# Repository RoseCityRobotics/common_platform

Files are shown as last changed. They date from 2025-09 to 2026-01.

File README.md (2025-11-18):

# Rose City Robotics Common Platform

> 📚 **📖 [View Complete Documentation](https://common.rosecityrobotics.com/)** - Comprehensive guides for setup, operation, and development

<!-- ABOUT THE PROJECT -->
## A Fork of the PARTS Common Platform

<br>
<p align="center">
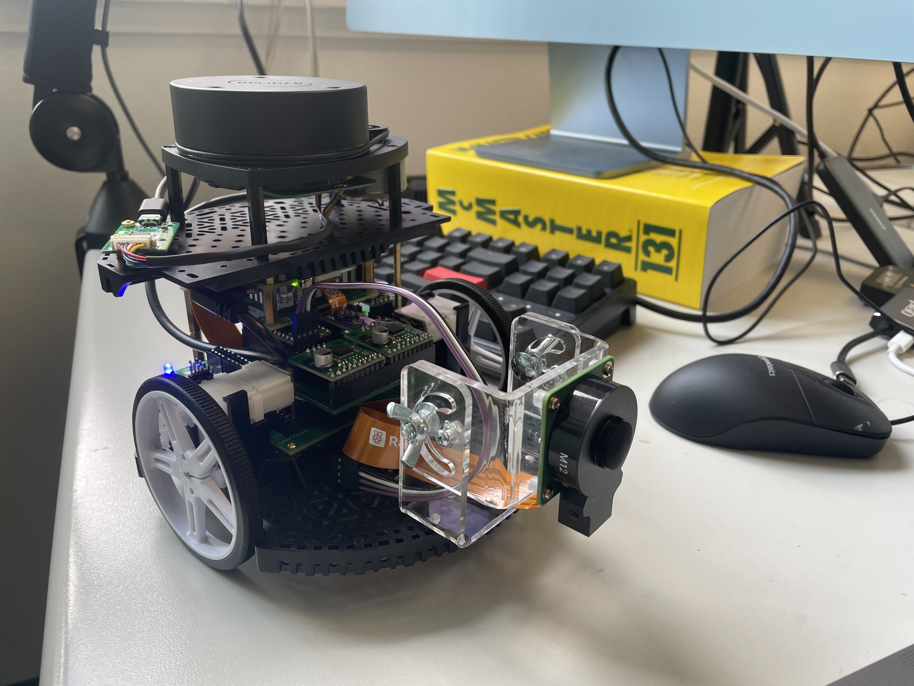
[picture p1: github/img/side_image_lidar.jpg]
Side view with LiDAR sensor
  
</p>
<br>

This project implements a complete robotics platform built on the Pololu Romi Chassis Kit, featuring a custom carrier PCB that integrates all components into a compact, efficient design. The platform combines hardware, firmware, and software to create a fully functional autonomous robot.

<br>
<p align="center">
  <a href="https://portlandrobotics.org/home.php?link_id=1">
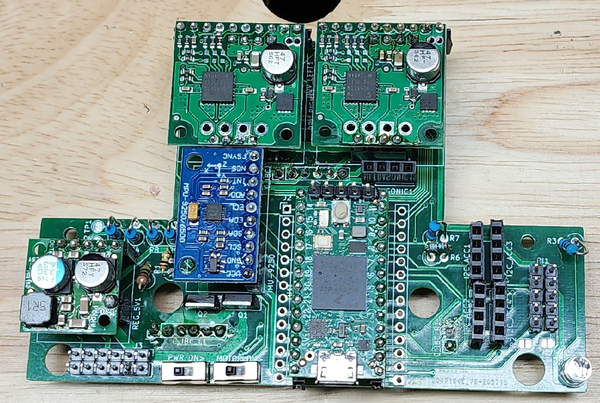
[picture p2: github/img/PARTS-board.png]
    
  </a>
<br>
<br>

**Hardware Components:**
- **Pololu Romi Chassis Kit** - Robust base platform with encoders and caster
- **Custom PARTS CRP Board** - Integrated carrier PCB with all connections
- **Teensy 4.0 Microcontroller** - High-performance ARM Cortex-M7 processor
- **TB9051FTG Motor Drivers** - Dual brushed DC motor control
- **MPU-9250 9DOF IMU** - Nine-axis motion sensing for navigation
- **Raspberry Pi with AI HAT** - Main computer for ROS2 and onboard autonomous vision inferance at 26 TOPS
- **Power Management** - 5V regulator and battery voltage monitoring

<br>
<p align="center">
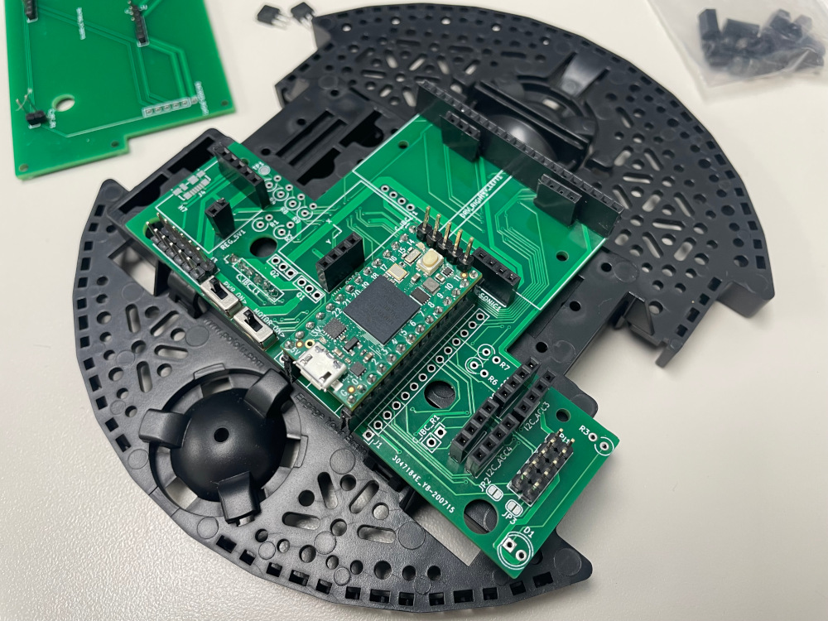
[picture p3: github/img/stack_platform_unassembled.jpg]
Mobile base platform
  
</p>
<br>

**Current Implementation:**
The platform now features a complete ROS2 integration with micro-ROS running on the Teensy 4.0, enabling real-time communication between the Raspberry Pi and the robot's sensors and actuators. The system supports autonomous navigation, sensor fusion, and closed-loop control, making it an ideal platform for robotics education and development in the Portland Area Robotics Society.

<p align="right">(<a href="#readme-top">back to top</a>)</p>

### Built With

* [][cpp-url]
* [][c-url]
* [][python-url]
* [][platformio-url]
* [][arduino-url]
* [][kicad-url]
* [][ros-url]

<p align="right">(<a href="#readme-top">back to top</a>)</p>

<!-- GETTING STARTED -->
## Getting Started

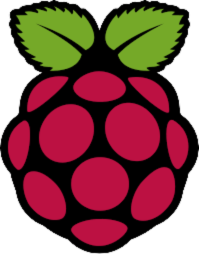
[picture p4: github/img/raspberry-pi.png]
Raspberry Pi
###  Direct Connection to Raspberry Pi
Connect your micro HDMI cable to your Pi and monitor, and a keyboard to the USB-A port.

OR

### 🖥️ On the development computer: Connect via SSH:
   ```bash
   ssh rcr@192.168.1.n
   ```
   Replace `n` with your robot number.

### Raspberry Pi Ubuntu Login on Raspberry Pi
- **User:** `rcr`
- **Password:** `siliconforest`

## 📚 Documentation

> **📖 [Complete Documentation](https://common.rosecityrobotics.com/)** - Comprehensive guides for setup, operation, and development

### Key Documentation Sections

- **🚀 [Getting Started](https://common.rosecityrobotics.com/)** - Complete setup from hardware assembly to first robot movement
- **⚙️ [Hardware Assembly](https://common.rosecityrobotics.com/hardware.html)** - Step-by-step soldering and assembly instructions
- **💻 [Software Setup](https://common.rosecityrobotics.com/setup/index.html)** - Host configuration, ROS2 installation, and Teensy programming
- **🎮 [Robot Operations](https://common.rosecityrobotics.com/operations/index.html)** - Startup, shutdown, teleoperation, and navigation procedures
- **🧪 [Testing & Validation](https://common.rosecityrobotics.com/testing.html)** - Smoke tests and system verification
- **🔧 [Troubleshooting](https://common.rosecityrobotics.com/operations/troubleshooting/index.html)** - Common issues and recovery procedures

### Quick Start Highlights

- **Hardware**: Custom PARTS CRP board with integrated motor drivers and Teensy 4.0
- **Software**: ROS2 with micro-ROS for real-time communication
- **Sensors**: LiDAR, IMU, and camera support for autonomous navigation
- **Programming**: Arduino CLI for Teensy firmware development
- **Testing**: Basic smoke test to verify hardware functionality

<p align="right">(<a href="#readme-top">back to top</a>)</p>

## 🤖 Imitation Learning Training

The platform includes a complete PyTorch training pipeline for robot maze navigation using imitation learning with a transformer-based architecture. For detailed documentation, see [`scripts/imitation_learning/src/imitation_learning/README.md`](scripts/imitation_learning/src/imitation_learning/README.md).

### Transfer Learning from No-Z Model Checkpoint

If you have a previously trained model without the Z variable (CVAE style variable) and want to initialize a new model with Z using those weights, you can use transfer learning:

```bash
# Navigate to the imitation learning directory
cd scripts/imitation_learning/src/imitation_learning

# Train with transfer learning from a no-Z model checkpoint
python train.py \
  --config config.yaml \
  --transfer_from_noz /path/to/best_model_without_z.pth
```

**What gets transferred:**
- ✅ Vision encoder weights
- ✅ Temporal encoder weights  
- ✅ Action decoder weights
- ✅ Action queries and action head weights
- 🆕 New CVAE components (`action_encoder`, `z_projection`) are randomly initialized

**Optional: Freeze layers during transfer learning**

You can freeze specific layers while training the new CVAE components by enabling transfer learning in your config:

```yaml
# In config.yaml
transfer_learning:
  enabled: true
  freeze_vision: true      # Freeze vision encoder
  freeze_encoder: false     # Keep temporal encoder trainable
  freeze_decoder: false     # Keep action decoder trainable
```

**Example: Freeze vision encoder only**
```bash
python train.py \
  --config config.yaml \
  --transfer_from_noz checkpoints/best_model_noz.pth
```

With `freeze_vision: true` in the config, the vision encoder will remain frozen while the new CVAE components and other layers are trained.

For more training options and examples, see the [imitation learning README](scripts/imitation_learning/src/imitation_learning/README.md).

<p align="right">(<a href="#readme-top">back to top</a>)</p>

### Assembly Images

*Mobile base platform - unassembled components*

Mobile base platform

*Assembled chassis with controller*

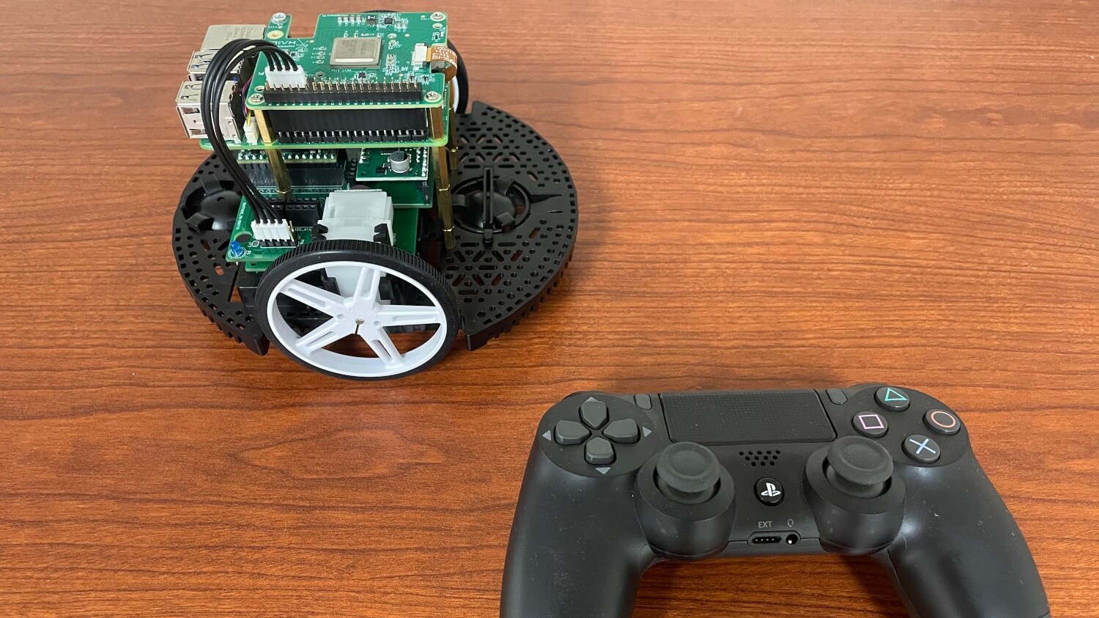
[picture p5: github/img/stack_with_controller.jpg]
Mobile base platform assembly


*Custom PCB showing integrated motor drivers and controller connections*

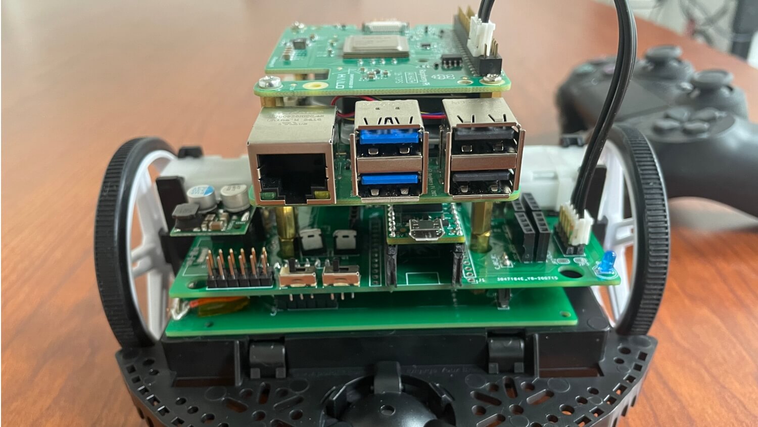
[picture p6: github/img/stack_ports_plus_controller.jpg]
Custom PCB with ports and controller


*Completed chassis - top view with Raspberry Pi AI HAT+*

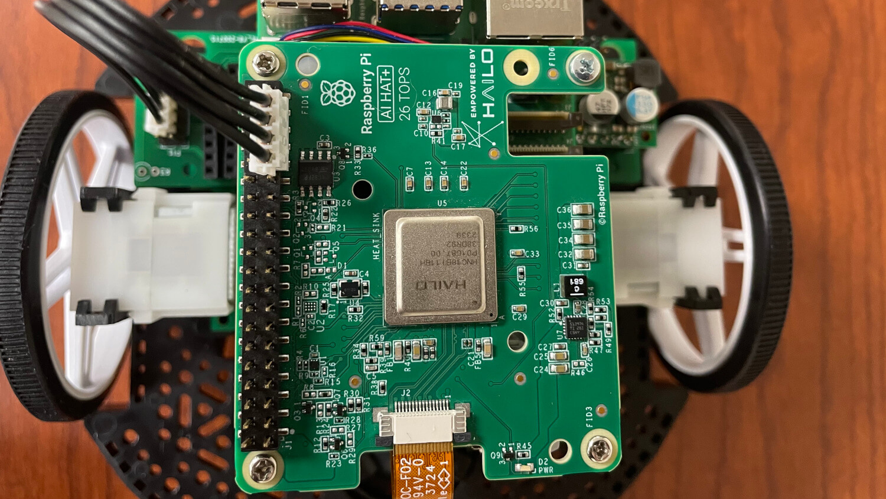
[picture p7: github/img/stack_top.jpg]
Assembled Platform - Top View


*Raspberry Pi 5 with AI HAT+*

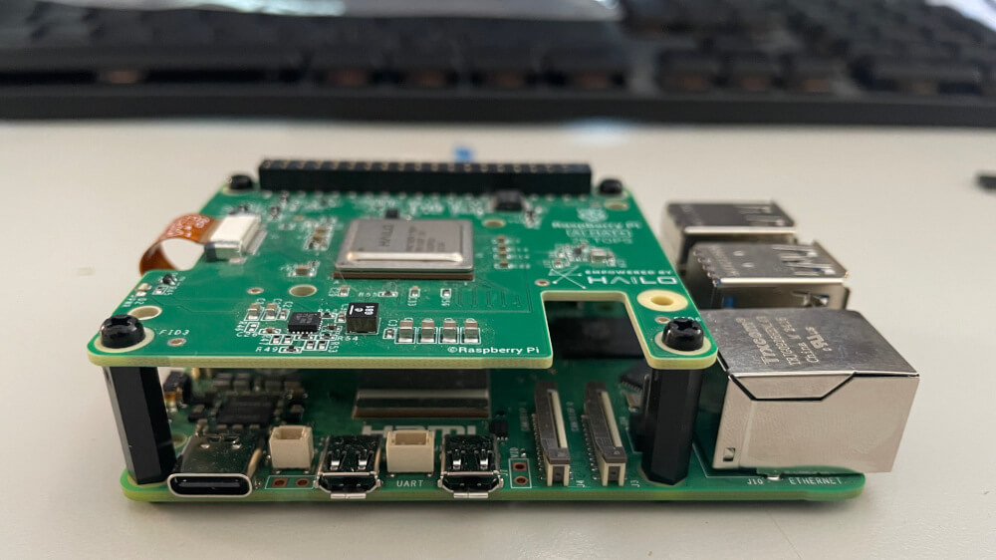
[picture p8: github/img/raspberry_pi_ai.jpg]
Raspberry Pi 5 with AI HAT+


*Side view with LiDAR sensor mounted*

Side view with LiDAR sensor

<p align="right">(<a href="#readme-top">back to top</a>)</p>

See the [open issues](https://github.com/rosecityrobotics/common_platform/issues) for a full list of proposed features (and known issues).

<p align="right">(<a href="#readme-top">back to top</a>)</p>

### Thank you PARTS

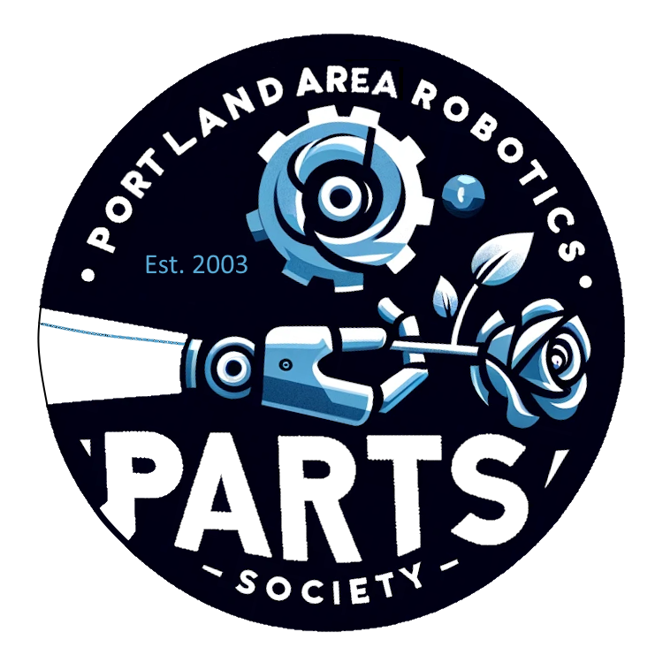
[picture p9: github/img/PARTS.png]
Portland Area Robotics Society (P.A.R.T.S.)


*Portland Area RoboTics Society (PARTS)*
Our work is based on the [PARTS Common Platform](https://github.com/portlandrobotics/common_platform)

<!-- CONTRIBUTING -->
## Contributing

Contributions are what make the open source community such an amazing place to learn, inspire, and create. Any contributions you make are **greatly appreciated**.

If you have a suggestion that would make this better, please fork the repo and create a pull request. You can also simply open an issue with the tag "enhancement".
Don't forget to give the project a star! Thanks again!

1. Fork the Project
2. Create your Feature Branch (`git checkout -b feature/AmazingFeature`)
3. Commit your Changes (`git commit -m 'Add some AmazingFeature'`)
4. Push to the Branch (`git push origin feature/AmazingFeature`)
5. Open a Pull Request

<p align="right">(<a href="#readme-top">back to top</a>)</p>

<!-- LICENSE -->
## License

Distributed under the MIT License and the Solderpad Hardware License v2.1. See [LICENSE.txt][license-url] for more information.

<p align="right">(<a href="#readme-top">back to top</a>)</p>

<!-- MARKDOWN LINKS & IMAGES -->
<!-- https://www.markdownguide.org/basic-syntax/#reference-style-links -->
[contributors-shield]: https://img.shields.io/github/contributors/portlandrobotics/common_platform.svg?style=for-the-badge
[contributors-url]: https://github.com/portlandrobotics/common_platform/graphs/contributors
[forks-shield]: https://img.shields.io/github/forks/portlandrobotics/common_platform.svg?style=for-the-badge
[forks-url]: https://github.com/portlandrobotics/common_platform/network/members
[stars-shield]: https://img.shields.io/github/stars/portlandrobotics/common_platform.svg?style=for-the-badge
[stars-url]: https://github.com/portlandrobotics/common_platform/stargazers
[issues-shield]: https://img.shields.io/github/issues/portlandrobotics/common_platform.svg?style=for-the-badge
[issues-url]: https://github.com/portlandrobotics/common_platform/issues
[license-shield]: https://img.shields.io/badge/license-mit_%26_solderpad-brightgreen?style=for-the-badge
[license-url]: https://github.com/portlandrobotics/common_platform/blob/master/LICENSE.txt
[arduino-ide]: https://img.shields.io/badge/Arduino_IDE-00979D?style=for-the-badge&logo=arduino&logoColor=white
[arduino-url]: https://www.arduino.cc/en/software
[cpp]: https://img.shields.io/badge/C%2B%2B-00599C?style=for-the-badge&logo=c%2B%2B&logoColor=white
[cpp-url]: https://en.wikipedia.org/wiki/C%2B%2B
[c]: https://img.shields.io/badge/C-00599C?style=for-the-badge&logo=c&logoColor=white
[c-url]: https://en.wikipedia.org/wiki/C_(programming_language)
[python]: https://img.shields.io/badge/Python-3776AB?style=for-the-badge&logo=python&logoColor=white
[python-url]: https://www.python.org/
[platformio]: https://img.shields.io/badge/PlatformIO-F5822A.svg?style=for-the-badge&logo=PlatformIO&logoColor=white
[platformio-url]: https://platformio.org/
[kicad]: https://img.shields.io/badge/KiCad-314CB0.svg?style=for-the-badge&logo=KiCad&logoColor=white
[kicad-url]: https://www.kicad.org/
[ros]: https://img.shields.io/badge/ROS-22314E.svg?style=for-the-badge&logo=ROS&logoColor=white
[ros-url]:https://www.ros.org/

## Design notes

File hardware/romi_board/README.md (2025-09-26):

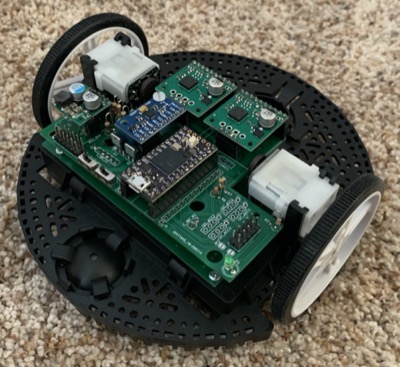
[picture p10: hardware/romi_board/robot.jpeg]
robot


## Assembly Notes

- In general, follow the instructions in the Romi chassis assembly [guide](https://www.pololu.com/docs/0J68/4).  Note that wheel encoders should be installed as shown in those instructions and will plug into the bottom board.
- The [interactive BOM](https://htmlpreview.github.io/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) is helpful while soldering components onto the board.
- We recommend using headers between the boards so that disassembly is possible.  Use female (socket) header on the bottom board and male (pin) headers on top board.  Pin headers come with all of the breakout boards.  
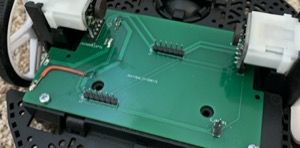
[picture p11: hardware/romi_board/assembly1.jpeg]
assembly1
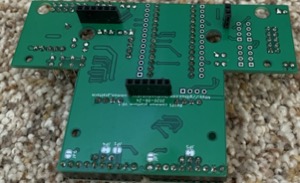
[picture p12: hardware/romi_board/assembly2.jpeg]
assembly2
 
- Use the top board to guide breakout board header soldering.  Insert the pin headers into the appropriate positions on the top board and then add the breakout boards onto the pins and solder them to the breakout boards. 
We recommend using socket headers on the top board for all of the breakout board positions so that they can be plugged in- Brace the IMU with extra header or cardboard or some other means.  Shown below is a 3D printed block but anything of the appropriate size will do.  
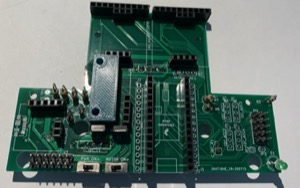
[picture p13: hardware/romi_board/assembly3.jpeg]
assembly3

- The three pin header on the motor driver is not needed and can be left without header pins.
- Pay attention to the orientation of the MOSFETs
- Use 2M ohm resistor for the battery voltage resistor divider (R1) if you use the 6 AA batteries.  If you use higher voltage batteries (2 LiPo batteries for example) then use a 3M ohm resistor.
- Cut trace on teensy for battery power.  See the note "Cut to separate VIN from VUSB" on the "Teensy 4.0 Back Side" image on this [page](https://www.pjrc.com/store/teensy40.html).
- If you want to mount a Raspberry Pi on the robot, this is how to use standoffs to do so:  
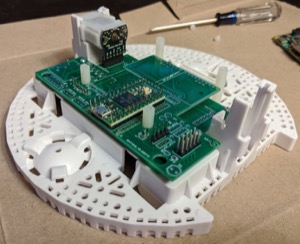
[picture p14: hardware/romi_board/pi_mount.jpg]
pi


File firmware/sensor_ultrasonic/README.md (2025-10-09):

# Ultrasonic Sensor Test

## Overview
This project involves using an Arduino/Teensy to test an HC-SR04 ultrasonic sensor. The `ultrasonic_test.ino` sketch measures the distance to an object and prints the result to the Serial Monitor.

## Requirements
- Arduino Compatible Device (Teensy, Uno, Mega, or similar)
- HC-SR04 Ultrasonic Sensor
- Jumper Wires

## Wiring
Connect the ultrasonic sensor to the Teensy 4.0:
- VCC to 5V
- GND to GND
- TRIG to Pin 9
- ECHO to Pin 15

OR

- Hook sensor to ULTRASONIC1 on Common Robotics Platform Main Board. Pin 1 VCC, Pin 2 Trigger, Pin 3 Echo, Pin 4 Ground. Looking at the RCR Common Robotics Platform board from the top, find the label "ULTRASONIC1" - Pin 1 is toward the U on ULTRASONIC1.
  - Ensure R6 3.3k and R7 4.6k resistors are installed so we don't burn out the teensy.

## Installation
1. Connect the Teensy/Arduino to your computer.
2. Open the `ultrasonic_test.ino` sketch in the Arduino IDE.
3. Upload the sketch to your Arduino board.

## Usage
After uploading the sketch, open the Serial Monitor in the Arduino IDE. You should see distance measurements displayed in centimeters, updated approximately every half second.

## Troubleshooting
- Ensure all connections are secure.
- Verify that the correct COM port is selected in the Arduino IDE.
- Ensure that your Arduino board is compatible with the sketch.

For more information or assistance, refer to the documentation of the HC-SR04 ultrasonic sensor and the Teensy/Arduino board being used.

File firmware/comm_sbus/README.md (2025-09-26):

# SBUS Test Readme

## Overview

The SBUS (Serial Bus) protocol is a digital communication protocol used in remote control equipment, particularly for communicating with RC (radio controlled) servos. It is favored for its efficiency and capability to handle multiple channels over a single wire. This README guides you through integrating SBUS control with our PARTS Robot using the [bolderflight/sbus](https://github.com/bolderflight/sbus) library.

Our project leverages the SBUS protocol to enable precise and responsive control over the PARTS Robot. By using SBUS, we can efficiently manage multiple control signals, such as steering and throttle, through a single digital connection. This approach simplifies wiring, increases reliability, and enhances the overall responsiveness of the robot. The SBUS library by Bolder Flight Systems provides a convenient and robust way to implement SBUS communication in our system, especially when interfaced with a Teensy microcontroller.

## Prerequisites
- A working installation of Teensy microcontroller.
- Basic understanding of SBUS communication protocol.
- A compatible SBUS transmitter and receiver.

## Installation and Setup

1. **Library Installation**: Download and install the sbus library from [bolderflight/sbus](https://github.com/bolderflight/sbus).

2. **Hardware Connection**: 
   - Connect the SBUS out on your receiver to an open Serial RX port on your Teensy. 
   - In this example, RX4 (Serial4) on the teansy, which is also connected to I2C2 on the common platform board, is used. Connect the yellow wire from your reciever here. 
   - Connect the red wire to 5V and the black wire to ground.  
   - Ensure that R8 on the common platform board is disconnected.

3. **Firmware Upload**:
   - Flash your Teensy with the firmware. You can find the firmware file `sbus_test.ino` in this repository. Click [here](./sbus_test.ino) to view or download it.

4. **Transmitter Setup**:
   - Configure your transmitter to output on Channels 1 and 2. Standard AETR configuration means the right stick will control the robot.
   - Ensure your transmitter is bound to your receiver.

5. **Receiver Configuration**:
   - Make sure the receiver is in SBUS mode and not CPPM.

6. **Power and Test**:
   - Power up the system and test the functionality.
   - Data is logged to USB serial for monitoring.

## Important Parameters

- **Serial Port Configuration**:
  To change the serial port, modify the following line in your code:

  ```cpp 
  bfs::SbusRx sbus_rx(&Serial4, true); // Setup SBUS using Serial4 (RX4), using a standard SBUS inverted signal
  ```

- **Channel Configuration**:
  To change the channels you are monitoring:

  ```cpp
  int linear = map(data.ch[1], 172, 1810, -MAX_PWM, MAX_PWM);  // Channel 2 for linear speed
  int angular = map(data.ch[0], 172, 1810, -MAX_PWM, MAX_PWM); // Channel 1 for angular speed
  ```

- **Maximum Speed Setting**:
  To change the maximum speed:

  ```cpp
  const int MAX_PWM = 200;        // Maximum PWM value for motor speed 0-255
  ```

## Tested Hardware

- Radiomaster Zorro jp4in1
- FRSky R-XSR Sbus Receiver

## Contributing

For any suggestions or contributions, please create an issue or pull request on the GitHub repository.

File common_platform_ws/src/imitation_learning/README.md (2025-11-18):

# Imitation Learning ROS2 Package

This ROS2 package provides imitation learning inference capabilities using trained models on Raspberry Pi 5, running inference on CPU using ONNX Runtime.

## Features

- Subscribes to `camera/image_raw` topic for input images
- Runs inference using ONNX Runtime with trained imitation learning model (ONNX format)
- Publishes velocity commands to `cmd_vel` topic at configurable rate (default: 30 Hz)
- Supports ROS2 namespaces via `ROS_NAMESPACE` environment variable
- Configurable model parameters, input dimensions, and velocity limits
- **Performance monitoring**: Tracks inference time, dropped frames, and reports statistics
- **Rate monitoring**: Warns if inference can't keep up with camera frame rate

## Dependencies

- ROS2 (Kilted)
- rclcpp
- sensor_msgs
- geometry_msgs
- std_msgs
- OpenCV4
- **ONNX Runtime C++ library** (see [ONNXRUNTIME_INSTALL.md](ONNXRUNTIME_INSTALL.md) for installation)
- ament_cmake

## Installation

### 1. Install ONNX Runtime

See [ONNXRUNTIME_INSTALL.md](ONNXRUNTIME_INSTALL.md) for detailed instructions on installing ONNX Runtime on Raspberry Pi 5 (Ubuntu 24 Server).

## Building

```bash
cd /home/rcr/repos/common_platform/common_platform_ws
colcon build --packages-select imitation_learning --symlink-install
source install/setup.bash
```

## Running

### Using launch file (recommended)

```bash
ros2 launch imitation_learning imitation_learning.launch.py
```

### With custom parameters

```bash
ros2 launch imitation_learning imitation_learning.launch.py \
  model_path:=/path/to/your/model.onnx \
  input_width:=224 \
  input_height:=224 \
  sequence_length:=10 \
  max_linear_velocity:=0.5 \
  max_angular_velocity:=1.5 \
  linear_velocity_threshold:=0.01 \
  angular_velocity_threshold:=0.05 \
  publish_rate:=30.0 \
  stats_report_interval:=10.0 \
  max_inference_time_ms:=33.0
```

### With namespace

```bash
ROS_NAMESPACE=/robot1 ros2 launch imitation_learning imitation_learning.launch.py
```

### Running the node directly

```bash
ros2 run imitation_learning imitation_learning_node
```

## Parameters

- `model_path`: Path to the ONNX model file (default: `/home/rcr/repos/common_platform/models/imitation_learning.onnx`)
- `input_width`: Input image width (default: 224)
- `input_height`: Input image height (default: 224)
- `sequence_length`: Number of consecutive frames for temporal model (default: 10)
- `max_linear_velocity`: Maximum linear velocity in m/s (default: 0.5)
- `max_angular_velocity`: Maximum angular velocity in rad/s (default: 1.5)
- `linear_velocity_threshold`: Threshold below which linear velocity is set to 0 (deadband) in m/s (default: 0.01)
- `angular_velocity_threshold`: Threshold below which angular velocity is set to 0 (deadband) in rad/s (default: 0.05)
- `publish_rate`: Publishing rate for cmd_vel in Hz (default: 30.0)
- `stats_report_interval`: Interval for reporting inference statistics in seconds (default: 10.0)
- `max_inference_time_ms`: Maximum expected inference time in milliseconds (default: 33.0, for 30 Hz camera)

## Topics

### Subscribed Topics

- `/camera/image_raw` (sensor_msgs/Image): Input images for inference

### Published Topics

- `/cmd_vel` (geometry_msgs/Twist): Velocity commands with linear.x and angular.z

## Model Compilation

See [MODEL_COMPILATION.md](MODEL_COMPILATION.md) for detailed instructions on converting PyTorch models to ONNX format.

## Usage Example

1. Ensure you have an ONNX model (see MODEL_COMPILATION.md)

2. Start the imitation learning node:
```bash
ros2 launch imitation_learning imitation_learning.launch.py \
  model_path:=/path/to/your/model.onnx
```

3. In another terminal, check the topics:
```bash
ros2 topic list
ros2 topic echo /cmd_vel
ros2 topic hz /cmd_vel
```

4. The node will automatically:
   - Subscribe to camera images
   - Run inference when enough frames are available
   - Publish cmd_vel commands at the specified rate (default 30 Hz)

## Architecture

The node maintains an image buffer to support temporal models that require sequences of images. When enough images are collected (based on `sequence_length`), inference is run and the predicted velocities are stored. A timer publishes these predictions at the configured rate (default 30 Hz) to ensure smooth control.

## Performance Monitoring

The node includes comprehensive performance monitoring:

- **Inference time tracking**: Measures and tracks min/max/average inference times
- **Dropped frame detection**: Monitors if frames arrive slower than expected
- **Rate monitoring**: Checks if inference rate matches camera rate
- **Periodic statistics**: Reports performance metrics every 10 seconds (configurable)

Example statistics output:
```
=== Inference Performance Stats (last 10 seconds) ===
  Total inferences: 300 (30.00 Hz)
  Avg inference time: 25.50 ms
  Min inference time: 22.10 ms
  Max inference time: 35.20 ms
  Dropped frames: 2
  ✓ Inference rate is sufficient for 30.0 Hz camera
```

If inference is too slow, you'll see warnings:
```
⚠ WARNING: Inference rate (25.00 Hz) is below expected rate (30.00 Hz)
```

## Troubleshooting

### ONNX Runtime Not Found

If the build fails to find ONNX Runtime, see [ONNXRUNTIME_INSTALL.md](ONNXRUNTIME_INSTALL.md) for installation instructions.

### External Data File Error

If you see an error like:
```
Exception during initialization: filesystem error: cannot get file size: No such file or directory [../models/best_model.onnx.data]
```

This means your ONNX model references an external data file (weights stored separately) but the file is missing or has a different name. Solutions:

1. **Re-export the model without external data** (recommended):
   ```python
   # In export_to_onnx.py, ensure external_data=False (default)
   torch.onnx.export(..., external_data=False)
   ```

2. **Copy the external data file** to match the name referenced in the ONNX file:
   - The error message shows which file is expected (e.g., `best_model.onnx.data`)
   - Copy your `.data` file to match that name in the same directory as the model

3. **Use a tool to fix the ONNX file** to point to the correct external data file name

### Inference Too Slow

If inference is too slow to keep up with the camera rate:
1. Check CPU usage and temperature
2. Consider reducing model complexity
3. Try quantizing the model to INT8
4. Reduce `sequence_length` if possible
5. Adjust thread counts in the code (currently 4 intra-op, 2 inter-op)

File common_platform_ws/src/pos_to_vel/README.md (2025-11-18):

# Odometry Calibration Node

This package provides a ROS2 node for calibrating robot odometry using discrete keyboard-controlled movements.

## Features

- **Discrete Actions**: Arrow keys trigger discrete movements (forward, turn+forward, etc.)
- **Action Calibration**: Adjust movement parameters in real-time using keyboard keys
- **Odometry Comparison**: Displays how well actual odometry readings match expected values after each action
- **Statistics Tracking**: Tracks position and orientation errors across multiple actions

## Usage

### Launch the Node

```bash
cd ~/code/common_platform/common_platform_ws
source install/setup.bash
ros2 launch pos_to_vel odom_calibration.launch.py
```

### With Namespace

```bash
ROS_NAME=robot1 ros2 launch pos_to_vel odom_calibration.launch.py
```

### With Custom Parameters

```bash
ros2 launch pos_to_vel odom_calibration.launch.py \
  forward_distance:=0.05 \
  turn_angle:=1.5708 \
  linear_speed:=0.3 \
  angular_speed:=0.5 \
  device_path:=/dev/input/event0
```

### Finding the Keyboard Device

If you need to find the correct device path for your USB keyboard dongle:

```bash
# List all input devices
ls -la /dev/input/

# Or use evtest to identify the keyboard
sudo evtest
```

The device path is typically `/dev/input/event0` for the first USB input device, but it may vary.

## Keyboard Controls

### Arrow Keys (Actions)
- **↑ (Up)**: Move forward by the set distance (default: 5 cm)
- **← (Left)**: Turn left 90° then move forward
- **→ (Right)**: Turn right 90° then move forward
- **↓ (Down)**: Turn 180° then move forward

### Calibration Adjustments
- **w/s**: Increase/decrease forward distance by 1 mm
- **a/d**: Increase/decrease turn angle by ~0.57°
- **q/e**: Increase/decrease linear speed by 1 cm/s
- **z/x**: Increase/decrease angular speed by 0.05 rad/s

### Other Controls
- **r**: Reset statistics
- **p**: Print current calibration values
- **h**: Show help/instructions
- **Ctrl+C**: Exit

## How It Works

1. When you press an arrow key, the node:
   - Records the current odometry position and orientation
   - Calculates the expected final position/orientation based on the action
   - Generates a sequence of `cmd_vel` commands to execute the action
   - Publishes commands to move the robot

2. After the action completes:
   - The robot stops
   - The node waits 0.5 seconds for odometry to settle
   - It compares actual vs expected position/orientation
   - Displays calibration results showing errors

3. You can adjust parameters in real-time:
   - Adjustments are applied to the next action
   - Use the adjustment keys to fine-tune movements
   - View current values with 'p' key

## Topics

### Subscribed
- `/scan` (sensor_msgs/LaserScan): LiDAR scan data
- `/odom` (nav_msgs/Odometry): Odometry data

### Published
- `/cmd_vel` (geometry_msgs/Twist): Velocity commands for robot movement

## Parameters

- `forward_distance` (default: 0.05 m): Distance to move forward in each action
- `turn_angle` (default: 1.5708 rad = 90°): Angle to turn for left/right actions
- `linear_speed` (default: 0.3 m/s): Speed for forward movement
- `angular_speed` (default: 0.5 rad/s): Speed for turning
- `scan_topic` (default: 'scan'): LiDAR scan topic name
- `odom_topic` (default: 'odom'): Odometry topic name
- `cmd_vel_topic` (default: 'cmd_vel'): Command velocity topic name
- `namespace` (default: ''): ROS namespace (can also use ROS_NAME env var)

## Calibration Process

1. Start the node and ensure odometry is publishing
2. Use arrow keys to execute discrete movements
3. Observe the calibration results after each action
4. If errors are consistent, use adjustment keys to fine-tune:
   - If robot moves too far/not far enough: adjust forward distance (w/s)
   - If turns are off: adjust turn angle (a/d)
   - If movements are too fast/slow: adjust speeds (q/e, z/x)
5. Repeat actions and check if errors decrease
6. Use 'r' to reset statistics and start fresh measurements

## Parameters

- `forward_distance` (default: 0.05 m): Distance to move forward in each action
- `turn_angle` (default: 1.5708 rad = 90°): Angle to turn for left/right actions
- `linear_speed` (default: 0.3 m/s): Speed for forward movement
- `angular_speed` (default: 0.5 rad/s): Speed for turning
- `scan_topic` (default: 'scan'): LiDAR scan topic name
- `odom_topic` (default: 'odom'): Odometry topic name
- `cmd_vel_topic` (default: 'cmd_vel'): Command velocity topic name
- `namespace` (default: ''): ROS namespace (can also use ROS_NAME env var)
- `device_path` (default: '/dev/input/event0'): Path to evdev input device for keyboard
- `grab_device` (default: true): Grab device exclusively to prevent events from going to console/X
- `debug` (default: true): Enable debug logging for keyboard events

## Notes

- **Keyboard Input**: The node uses `evdev` to read from a USB keyboard dongle connected directly to the Raspberry Pi
- The keyboard must be connected via USB dongle (not through SSH terminal)
- Each action completes fully before the next can be executed
- The robot stops after each discrete movement
- Calibration adjustments are cumulative and persist until reset
- If the device path is incorrect, check `/dev/input/` to find the correct event device

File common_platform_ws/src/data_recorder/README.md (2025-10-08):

# Data Recorder Package

A ROS2 package for recording synchronized camera images and motor velocity data during teleoperation for neural network training.

## Features

- **Synchronized Data Capture**: Records camera images and motor velocities at 30 Hz with precise timestamps
- **Multiple Output Formats**: Supports HDF5, NumPy, and TFRecord formats for machine learning
- **Real-time Control**: Start/stop recording via ROS2 topics or launch parameters
- **Data Validation**: Built-in validation to ensure data integrity
- **Flexible Configuration**: Configurable topics, recording rates, and output directories

## Quick Start

### 1. Build the Package

```bash
cd /home/rcr/repos/common_platform/common_platform_ws
colcon build --packages-select data_recorder
source install/setup.bash
```

### 2. Launch the Data Recorder

```bash
# Basic launch (manual start/stop) - uses libcamera by default
ros2 launch data_recorder data_recorder.launch.py

# Auto-start recording
ros2 launch data_recorder data_recorder.launch.py auto_start:=true

# Custom output directory
ros2 launch data_recorder data_recorder.launch.py output_dir:=/path/to/your/data

# Use v4l2 camera instead of libcamera
ros2 launch data_recorder data_recorder.launch.py camera_type:=v4l2

# Launch with camera and data recorder together (recommended)
ros2 launch data_recorder data_recorder_with_camera.launch.py

# Launch with libcamera (Pi HQ Camera)
ros2 launch data_recorder data_recorder_with_camera.launch.py camera_type:=libcamera

# Launch with v4l2 camera
ros2 launch data_recorder data_recorder_with_camera.launch.py camera_type:=v4l2

# Launch with namespace support (for multi-robot setups)
ROS_NAMESPACE=robot1 ros2 launch data_recorder data_recorder_with_camera.launch.py
```

### 3. Control Recording

```bash
# Start recording
python3 /path/to/data_recorder/scripts/record_control.py start

# Stop recording
python3 /path/to/data_recorder/scripts/record_control.py stop

# Check status
python3 /path/to/data_recorder/scripts/record_control.py status
```

### 4. Process Data for Training

```bash
# Process a recording session
python3 /path/to/data_recorder/scripts/process_training_data.py /path/to/session_directory

# Validate data only
python3 /path/to/data_recorder/scripts/process_training_data.py /path/to/session_directory --validate-only

# Process with custom output format
python3 /path/to/data_recorder/scripts/process_training_data.py /path/to/session_directory --output-format hdf5
```

## Data Format

### Recorded Data Structure

Each recording session creates a timestamped directory with:

```
session_YYYYMMDD_HHMMSS/
├── images/
│   ├── 00000000.jpg
│   ├── 00000001.jpg
│   └── ...
└── metadata/
    └── data_log.csv
```

### CSV Data Format

The `data_log.csv` contains:

| Column | Description | Units |
|---|---|---|
| timestamp | Microsecond timestamp | μs |
| image_file | Image filename | - |
| linear_vel | Linear velocity | m/s |
| angular_vel | Angular velocity | rad/s |
| left_wheel_vel | Left wheel velocity | rad/s |
| right_wheel_vel | Right wheel velocity | rad/s |

### Processed Data Formats

After processing, you get:

- **HDF5**: `training_data.h5` with 'images' and 'labels' datasets
- **NumPy**: `images.npy` and `labels.npy` arrays
- **TFRecord**: Conversion script for TensorFlow training
- **Statistics**: `statistics.json` with dataset statistics

## Configuration

### Launch Parameters

| Parameter | Default | Description |
|---|---|---|
| `output_dir` | `/home/rcr/teleop_data` | Output directory for recordings |
| `camera_topic` | `/camera/image_raw` | Camera topic to record |
| `cmd_vel_topic` | `/cmd_vel` | Command velocity topic |
| `record_rate` | `30.0` | Recording rate in Hz |
| `auto_start` | `false` | Auto-start recording on launch |
| `use_sim_time` | `false` | Use simulation time |
| `camera_type` | `libcamera` | Camera type: `libcamera` or `v4l2` |
| `camera_id` | `0` | Camera ID for libcamera |
| `pixel_format` | `""` | Pixel format (empty for default) |

### Namespace Support

The data recorder supports ROS2 namespaces for multi-robot setups:

- **Environment Variable**: Set `ROS_NAMESPACE` to enable namespace support
- **Topic Namespacing**: Topics are automatically prefixed with the namespace
- **Node Namespacing**: Nodes are placed in the specified namespace

**Example:**
```bash
# Single robot (no namespace)
ros2 launch data_recorder data_recorder_with_camera.launch.py

# Multi-robot setup
ROS_NAMESPACE=robot1 ros2 launch data_recorder data_recorder_with_camera.launch.py
ROS_NAMESPACE=robot2 ros2 launch data_recorder data_recorder_with_camera.launch.py
```

**With namespace `robot1`, topics become:**
- `/robot1/camera/image_raw`
- `/robot1/cmd_vel`
- `/robot1/data_recorder/start_stop`

### Robot Parameters

The recorder uses these robot parameters (from your config):

- **Wheel Separation**: 0.297 meters
- **Wheel Radius**: 0.033 meters

These are used to convert linear/angular velocities to individual wheel velocities.

### Camera Support

The data recorder supports both camera types:

#### libcamera (Recommended for Pi HQ Camera)
- **Default**: Uses libcamera for better image quality and control
- **Compatible**: Pi HQ Camera (IMX477), Pi Camera v2/v3
- **Benefits**: Better image quality, hardware ISP, automatic exposure control
- **Usage**: `camera_type:=libcamera`

#### v4l2 (Legacy support)
- **Compatible**: USB cameras, older Pi cameras
- **Usage**: `camera_type:=v4l2`

## Topics

### Subscribed Topics

- `/camera/image_raw` (sensor_msgs/Image): Camera images
- `/cmd_vel` (geometry_msgs/Twist): Motor commands
- `/data_recorder/start_stop` (std_msgs/Bool): Recording control

### Published Topics

- `/data_recorder/status` (std_msgs/Bool): Recording status

## Usage Examples

### Basic Teleoperation Recording

1. Start your robot system:
```bash
ros2 launch common_platform launch_robot.launch.py
```

2. Start the data recorder:
```bash
ros2 launch data_recorder data_recorder.launch.py
```

3. Start teleoperation (joystick, keyboard, etc.):
```bash
ros2 launch common_platform joystick.launch.py
```

4. Control recording:
```bash
# Start recording
python3 /path/to/record_control.py start

# Drive your robot around...

# Stop recording
python3 /path/to/record_control.py stop
```

### Batch Processing Multiple Sessions

```bash
# Process all sessions in a directory
for session in /path/to/data/session_*; do
  echo "Processing $session"
  python3 /path/to/process_training_data.py "$session"
done
```

### Custom Training Pipeline

```python
import h5py
import numpy as np

# Load processed data
with h5py.File('training_data.h5', 'r') as f:
    images = f['images'][:]
    labels = f['labels'][:]

# Split into train/validation
split_idx = int(0.8 * len(images))
train_images = images[:split_idx]
train_labels = labels[:split_idx]
val_images = images[split_idx:]
val_labels = labels[split_idx:]

# Your neural network training code here...
```

## Troubleshooting

### Common Issues

1. **No images being recorded**: Check that the camera topic is publishing
2. **No velocity data**: Verify the cmd_vel topic is active
3. **Permission errors**: Ensure write permissions to output directory
4. **High CPU usage**: Reduce recording rate or image resolution

### Debug Commands

```bash
# Check if topics are publishing
ros2 topic list
ros2 topic hz /${ROS_NAME}/camera/image_raw
ros2 topic hz /${ROS_NAME}/cmd_vel

# Monitor recording status
ros2 topic echo /${ROS_NAME}/data_recorder/status

# Check node status
ros2 node list
ros2 node info /${ROS_NAME}/data_recorder
```

## Performance Considerations

- **Storage**: Each session can generate 100MB+ per minute (640x480 images at 30Hz)
- **CPU**: Image processing and file I/O can be CPU intensive
- **Memory**: Large datasets may require significant RAM for processing

## Integration with Your Robot

The data recorder is designed to work with your existing robot setup:

- Uses your camera topic: `/camera/image_raw`
- Records direct motor commands: `/cmd_vel`
- Compatible with your joystick teleoperation
- Respects your robot's physical parameters

## YOLO Training with Label Studio

The data recorder is perfect for YOLO object detection training! Images are already saved in JPG format, which is exactly what Label Studio expects.

### Complete YOLO Workflow:

1. **Record Data**:
   ```bash
   ros2 launch data_recorder data_recorder_with_camera.launch.py camera_type:=libcamera
   python3 install/data_recorder/lib/data_recorder/record_control.py start
   # Drive around and collect data
   python3 install/data_recorder/lib/data_recorder/record_control.py stop
   ```

2. **Prepare for Label Studio**:
   ```bash
   python3 install/data_recorder/lib/data_recorder/prepare_for_labelstudio.py /path/to/session_directory
   ```

3. **Annotate in Label Studio**:
   - Import the generated `manifest.json` file
   - Draw bounding boxes around objects
   - Export in YOLO format

4. **Combine with Motor Data**:
   ```bash
   python3 install/data_recorder/lib/data_recorder/combine_yolo_with_motor_data.py /path/to/session_directory /path/to/yolo_annotations
   ```

5. **Train YOLO Model**:
   ```bash
   cd /path/to/combined_dataset
   python3 train_yolo.py
   ```

### Benefits for YOLO Training:

- ✅ **Perfect Image Format**: JPG files ready for Label Studio
- ✅ **Motion Filtering**: Only annotate images with robot movement
- ✅ **Motor Commands**: Combine object detection with navigation data
- ✅ **End-to-End Learning**: Train models that see objects and predict actions
- ✅ **High Quality**: libcamera provides excellent image quality for detection

## Future Enhancements

Potential improvements:

- Real-time data visualization
- Automatic data quality assessment
- Integration with popular ML frameworks
- Support for additional sensor data (IMU, LiDAR, etc.)
- Data augmentation during recording
- Automatic object detection during recording

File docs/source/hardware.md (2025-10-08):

# Hardware Assembly Guide

#### Solder Your PARTS CRP Board
Soldering the PARTS CRP board is the first crucial step. Follow the instructions carefully to ensure a successful setup.

- **Interactive BOM**: Utilize the [Interactive BOM](https://htmlpreview.github.io/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) for an easier soldering process.
- **Headers for Connectivity**: We recommend using headers for connections between boards. This makes disassembly possible if needed.
  - Use female (socket) headers on the bottom board.
  - Use male (pin) headers on the top board. These are typically included with all breakout boards.
- **MOSFET Orientation**: Ensure the correct orientation of the MOSFETs during soldering.
- **Resistor for Battery Voltage Divider**: Choose the resistor based on your battery choice:
  - Use a 2M ohm resistor (R1) for 6 AA batteries.
  - Opt for a 3M ohm resistor if using higher voltage batteries like 2 LiPo batteries.
  - Install a >100 pf capacitor across R2 to address voltage drop issues.
- **Teensy Board Modification**: For battery power, cut the trace on the Teensy board. Refer to the note "Cut to separate VIN from VUSB" on the [Teensy 4.0 Back Side](https://github.com/rosecityrobotics/common_platform/blob/master/hardware/main_schematic.pdf) image.
- **Resistor Values**: The values of R4, R5, R8, R9 depend on your specific usage. For I2C, 4.7k is appropriate.
- **Schematic**: Refer to the [Main Schematic](https://github.com/rosecityrobotics/common_platform/blob/master/hardware/main_schematic.pdf) for detailed understanding.

#### Solder Accessories
Solder accessories like the Inertial Measurement Unit (IMU), ensuring proper orientation and connection.

#### Assemble the Pololu Romi Chassis
The Pololu Romi Chassis forms the physical structure of your robot.

- Follow the [Romi Chassis Assembly Guide](https://www.pololu.com/docs/0J68/4) for detailed instructions on assembling the chassis.

### Starting with the Basic Test

**Flash the Teensy 4.0 Board:**
Begin by flashing the Teensy 4.0 board with the basic test code found in the repository at `/firmware/basic_test/basic_test.ino`. This initial test is crucial for validating your setup.

**Expected Behavior:**
Upon successful flashing, the robot should exhibit a simple behavior pattern: moving forward, pausing, and then moving backward.

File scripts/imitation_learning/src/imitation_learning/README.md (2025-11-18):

# Maze Navigation Imitation Learning

This directory contains a complete PyTorch training pipeline for robot maze navigation using imitation learning with a transformer-based Action Chunking architecture adapted from ALOHA.

## Overview

The system trains a neural network to predict robot actions (linear and angular velocities) from sequences of camera images. The model uses:

- **Vision Encoder**: ResNet/EfficientNet backbone for image feature extraction
- **Temporal Encoder**: Transformer encoder for sequence processing
- **Action Decoder**: Transformer decoder with learned queries for action chunking

## Quick Start

### 1. Install Dependencies

```bash
pip install -r requirements.txt
```

### 2. Prepare Data

Ensure your data is collected using the `data_recorder` package and organized as:

```
/home/rcr/teleop_data/
├── session_20240101_120000/
│   ├── images/
│   │   ├── 00000000.jpg
│   │   ├── 00000001.jpg
│   │   └── ...
│   └── metadata/
│       └── data_log.csv
├── session_20240101_130000/
└── ...
```

### 3. Train Model

```bash
# Basic training
python train.py --config config.yaml

# With custom data path
python train.py --config config.yaml --data_root /path/to/your/data

# Resume from checkpoint
python train.py --config config.yaml --resume checkpoints/checkpoint_epoch_0100.pth
```

### 4. Evaluate Model

```bash
# Evaluate on test set
python evaluate.py --checkpoint checkpoints/best_model.pth --config config.yaml

# With custom output directory
python evaluate.py --checkpoint checkpoints/best_model.pth --output_dir results/
```

## Configuration

Edit `config.yaml` to customize training:

### Key Parameters

- **Dataset**: Data paths, sequence length, chunk size
- **Model**: Architecture, backbone, transformer layers
- **Training**: Learning rate, batch size, epochs, optimization
- **Transfer Learning**: ALOHA weight loading, layer freezing

### Example Configuration

```yaml
dataset:
  data_root: "/home/rcr/teleop_data"
  sequence_length: 10      # Number of input frames
  chunk_size: 15           # Actions to predict per frame
  image_size: [224, 224]   # Input image size

model:
  backbone: "resnet18"     # Vision backbone
  d_model: 512            # Transformer dimension
  chunk_size: 15          # Action chunk size

training:
  batch_size: 16
  learning_rate: 1e-4
  num_epochs: 100
```

## Transfer Learning

### Load ALOHA Pretrained Weights

```bash
# Analyze ALOHA checkpoint
python transfer_learning.py --checkpoint aloha_model.pth --analyze

# Create fine-tuning config
python transfer_learning.py --checkpoint aloha_model.pth --create-config fine_tune_config.yaml

# Train with ALOHA weights
python train.py --config fine_tune_config.yaml --pretrained aloha_model.pth
```

### Fine-tuning Options

- **Freeze Vision**: Keep pretrained vision encoder frozen
- **Freeze Encoder**: Keep temporal encoder frozen
- **Freeze Decoder**: Keep action decoder frozen
- **Full Fine-tuning**: Train all layers with lower learning rate

## Data Format

The system expects data in the format produced by `data_recorder_node.cpp`:

### CSV Format (`data_log.csv`)
```csv
timestamp,image_file,linear_vel,angular_vel,position_x,position_y,orientation_z,cmd_linear_x,cmd_angular_z
1234567890,00000000.jpg,0.1,0.05,1.0,2.0,0.1,0.2,0.1
```

### Image Format
- **Format**: JPG files in `images/` subdirectory
- **Size**: 640x480 (resized to 224x224 during training)
- **Color**: RGB (converted from BGR by data recorder)

## Model Architecture

### Action Chunking Transformer

```
Input: (batch, seq_len, 3, H, W) - Image sequences
  ↓
Vision Encoder: ResNet/EfficientNet
  ↓
Features: (seq_len, batch, d_model)
  ↓
Temporal Encoder: Transformer layers
  ↓
Contextualized Features: (seq_len, batch, d_model)
  ↓
Action Decoder: Cross-attention with learned queries
  ↓
Output: (batch, seq_len, chunk_size, 2) - Action chunks
```

### Key Features

- **Temporal Processing**: Handles variable-length sequences
- **Action Chunking**: Predicts multiple future actions per frame
- **Transfer Learning**: Compatible with ALOHA pretrained weights
- **Efficient Training**: Mixed precision, gradient clipping, early stopping

## Training Process

### 1. Data Loading
- Loads multiple session directories
- Creates temporal windows of consecutive frames
- Applies data augmentation (training only)
- Normalizes actions using training statistics

### 2. Model Training
- MSE loss between predicted and target action chunks
- AdamW optimizer with cosine annealing
- Mixed precision training for efficiency
- Gradient clipping for stability

### 3. Validation
- Evaluates on held-out validation set
- Computes comprehensive metrics
- Early stopping based on validation loss
- Saves best model checkpoint

### 4. Evaluation
- Tests on held-out test set
- Generates detailed analysis plots
- Computes correlation and error metrics
- Creates summary reports

## Output Files

### Training Outputs
```
outputs/experiment_20240101_120000/
├── config.yaml                    # Training configuration
├── experiment_info.json           # Model and experiment info
├── checkpoints/                   # Model checkpoints
│   ├── best_model.pth
│   ├── checkpoint_epoch_0050.pth
│   └── final_model.pth
├── tensorboard/                   # TensorBoard logs
├── training_curves.png            # Loss curves
└── predictions_epoch_*.png        # Sample predictions
```

### Evaluation Outputs
```
evaluation_results/
├── model_action_predictions.png   # Prediction vs target plots
├── model_action_chunks.png        # Action chunk analysis
├── model_detailed_analysis.png    # Comprehensive analysis
├── model_chunk_analysis.png       # Temporal analysis
├── model_metrics.json             # Quantitative metrics
└── model_summary_report.txt       # Human-readable summary
```

## Usage Examples

### Basic Training
```bash
# Train with default settings
python train.py

# Train with custom config
python train.py --config my_config.yaml

# Train with specific data path
python train.py --data_root /path/to/data --output_dir /path/to/output
```

### Transfer Learning
```bash
# Analyze ALOHA checkpoint
python transfer_learning.py --checkpoint aloha_weights.pth --analyze

# Create fine-tuning configuration
python transfer_learning.py --checkpoint aloha_weights.pth --create-config aloha_finetune.yaml

# Train with ALOHA weights
python train.py --config aloha_finetune.yaml --pretrained aloha_weights.pth
```

### Evaluation
```bash
# Evaluate best model
python evaluate.py --checkpoint checkpoints/best_model.pth

# Evaluate with custom settings
python evaluate.py --checkpoint checkpoints/best_model.pth --batch_size 32 --num_samples 1000
```

### Resume Training
```bash
# Resume from specific checkpoint
python train.py --resume checkpoints/checkpoint_epoch_0050.pth

# Resume with different config
python train.py --config new_config.yaml --resume checkpoints/best_model.pth
```

## Troubleshooting

### Common Issues

1. **CUDA Out of Memory**
   - Reduce batch size in config
   - Use mixed precision training
   - Reduce image size or sequence length

2. **No Data Found**
   - Check data_root path in config
   - Ensure session directories exist
   - Verify CSV files have correct format

3. **Poor Performance**
   - Increase training data
   - Adjust learning rate
   - Try different backbone (ResNet34, EfficientNet)
   - Use transfer learning from ALOHA

4. **Slow Training**
   - Increase num_workers in dataloader
   - Use mixed precision training
   - Reduce image size
   - Use GPU if available

### Debug Commands

```bash
# Check data loading
python -c "from dataset import create_datasets; train, val, test = create_datasets('/path/to/data'); print(f'Train: {len(train)}, Val: {len(val)}, Test: {len(test)}')"

# Check model architecture
python -c "from model import create_model; import yaml; config = yaml.safe_load(open('config.yaml')); model = create_model(config); print(model.get_model_info())"

# Analyze checkpoint
python transfer_learning.py --checkpoint your_checkpoint.pth --analyze
```

## Performance Tips

1. **Data Quality**: Ensure high-quality teleoperation data
2. **Data Quantity**: Collect at least 50+ sessions for good performance
3. **Augmentation**: Use data augmentation to improve generalization
4. **Transfer Learning**: Start with ALOHA pretrained weights
5. **Hyperparameter Tuning**: Experiment with learning rates and model sizes
6. **Regularization**: Use dropout and weight decay to prevent overfitting

## Integration with Robot

After training, integrate the model with your robot:

```python
import torch
from model import create_model, load_pretrained_weights

# Load trained model
model = create_model(config)
model = load_pretrained_weights(model, 'checkpoints/best_model.pth')
model.eval()

# Process robot camera feed
def predict_action(image_sequence):
    with torch.no_grad():
        actions = model.predict_actions(image_sequence, use_first_action_only=True)
        return actions[0, -1, :]  # Return last frame's first action
```

## Contributing

1. Follow the existing code structure
2. Add comprehensive docstrings
3. Include type hints
4. Test with small datasets first
5. Update documentation for new features

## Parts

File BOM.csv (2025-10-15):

Name | Quantity | Description | Price (each) | Total | URL
Motor Driver | 2 | TB9051FTG Single Brushed DC Motor Driver Carrier | $11.95 | $23.90 | https://www.pololu.com/product/2997/resources
Voltage Regulator | 1 | Pololu 5V, 2.5A Step-Down Voltage Regulator D24V22F5 | $8.95 | $8.95 | https://www.pololu.com/product/2858/resources
IMU | 1 | MPU-9250 9DOF Module Nine-axis | $14.99 | $14.99 | https://www.amazon.com/HiLetgo-Gyroscope-Acceleration-Accelerator-Magnetometer/dp/B01I1J0Z7Y
Chassis | 1 | Romi Chasis Kit | $39.95 | $39.95 | https://www.pololu.com/category/203/romi-chassis-kits
Wheel Encoders | 1 | Romi Encoder (pair) | $9.95 | $9.95 | https://www.pololu.com/product/3542
Caster | 1 | Romi Chasis Caster | $3.95 | $3.95 | https://www.pololu.com/product/3530
Processor | 1 | Teensy 4.0 | $23.80 | $23.80 | https://www.pjrc.com/store/teensy40.html
Switch | 2 | SPDT slide switch | $1.69 | $3.38 | https://www.pololu.com/product/1408
MOSFET | 2 | MOSFET | $0.86 | $1.72 | https://www.digikey.com/product-detail/en/infineon-technologies/IRFU5505PBF/IRFU5505PBF-ND/812417
AI Compute | 1 | Raspberry Pi AI HAT+ 26 TOPS | $119.95 | $119.95 | https://www.pishop.us/product/raspberry-pi-ai-hat-26-tops/
Computer | 1 | Raspberry Pi 5 / 16 GB with active cooler and power supply | $144.90 | $144.90 | https://www.pishop.us/product/raspberry-pi-5-16gb/
Pi HQ Camera | 1 | Raspberry Pi HQ Camera M12 SKU: 942-1: 2.7mm 12MP Wide-Angle Lens SKU: 819-1: Universal Tilt-Adjustable Mount | $97.85 | $97.85
Motor Control PCB | 1 | Custom PCB to mount motor controller and Teensy | $20.00 | $20.00 | https://github.com/portlandrobotics/common_platform/tree/665b2a9ae5a72f6d04d19fb59966c4b148ab0bfb/hardware/romi_board
Lidar | 1 | Slamtec RPLIDAR A1M8-R6 | $89.60 | $89.60 | https://www.amazon.com/dp/B0923RYT8V?ref=ppx_yo2ov_dt_b_fed_asin_title
Camera Cable | 1 | Camera cable for Raspberry Pi 5 | $2.65 | $2.65 | https://www.pishop.us/product/camera-cable-for-raspberry-pi-5/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
Chassis Expansion | 1 | Romi Chassis Expansion Plate | $6.49 | $6.49 | https://www.pololu.com/product/3560/specs
Standoffs |  | M2 20 mm |  | $0.00
Standoffs |  | M2 5 mm |  | $0.00
Standoffs | 4 | M2.5 15 mm |  | $0.00
Standoffs | 4 | M2.5 5 mm |  | $0.00
Standoffs | 2 | M2.5 10 mm |  | $0.00
 |  |  |  | $0.00
 |  |  |  | $0.00
Hardware |  | M2 screws |  | $0.00
Hardware |  | M2 nuts |  | $0.00
Hardware |  | M2.5 screws |  | $0.00
Hardware |  | M2.5 nuts |  | $0.00
Batteries | 1 | 8-Pack Rechargeable AA Batteries with Dual-Mode Charger for Lithium & NiMH Batteries 3600mWh High Capacity AA Li-ion Battery | $22.50 | $22.50 | https://www.amazon.com/dp/B0DRVBK4LC?ref=ppx_yo2ov_dt_b_fed_asin_title
Storage |  | MicroSD card 128GB Amazon Basics | $11.99 | $0.00 | https://www.amazon.com/gp/product/B08TJRVWV1/ref=ox_sc_act_title_1?smid=A2Q1LRYTXHYQ2K&th=1
Power cord |  | USB C to 2 pin bare wire | $2.48 | $0.00 | https://www.amazon.com/dp/B0CY2J5H3K?ref=fed_asin_title&th=1
Wire |  | red/black 18 gauge | $0.10 | $0.00 | https://www.amazon.com/GS-Power-Automotive-Spool-Red-Electrical/dp/B07D74RGVM?s=electronics
Header | 1 | female 1 position |  | $0.00
Header | 1 | female 2 position |  | $0.00
Header | 2 | female 3 position |  | $0.00
Header | 2 | female 4 position |  | $0.00
Header | 1 | female 5 position |  | $0.00
Header | 2 | female 6 position |  | $0.00
Header | 2 | female 10 position |  | $0.00
Header | 2 | female 14 position |  | $0.00
Header | 5 | male 4 position |  | $0.00
Header | 1 | male 10 position, 2 rows |  | $0.00
Header | 1 | male 12 position, 2 rows |  | $0.00
Header | 1 | male 2 position |  | $0.00
Header | 2 | male 6 position |  | $0.00
Header | 2 | male 14 position |  | $0.00
Resistor | 4 | 4.7 kOhms, 1/4 watt |  | $0.00
Resistor | 1 | 2 MOhms, 1/4 watt |  | $0.00
Resistor | 1 | 1 MOhms, 1/4 watt |  | $0.00
Resistor | 2 | 10 kOhms, 1/4 watt (comes with ultrasonic sensor) | $0.00 | $0.00
Resistor | 1 | 1 kOhm, 1/4 watt |  | $0.00
LED | 1 | green light power on |  | $0.00
Capacitor | 4 | .1 nF, SMD:C_0805_2012Metric_Pad1.18x1.45mm_HandSolder |  | $0.00
Capacitor | 1 | 470 uF, THT:CP_Radial_D6.3mm_P2.50mm |  | $0.00
Capacitor | 1 | .1 uF, THT:C_Disc_D5.0mm_W2.5mm_P5.00mm |  | $0.00
Ultrasonic Sensor | 1 | HC-SR04 |  | $0.00
Ultrasonic Sensor Mount | 1 | Mount for ultrasonic sensor | $1.75 | $1.75 | https://www.ebay.com/itm/224786207610
Input | 1 | Logitec Keyboard/Mouse | $24.99 | $24.99
Heat Shrink | 2 | red/black 1/8" | $0.21 | $0.42
Display Cable | 1 | Micro HDMI to HDMI, 6 ft | $7.45 | $7.45 | https://www.pishop.us/product/microhdmi-hdmi-cable-6ft/
Lidar Cable | 1 | Micro USB to USB A male | $2.95 | $2.95 | https://www.pishop.us/product/usb-a-male-to-usb-micro-b-cable-6-inches/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
Teensy Cable | 1 | L-Micro USB to USB A male | $2.95 | $2.95 | https://www.pishop.us/product/usb-2-0-a-male-to-l-shape-micro-b-male-cable-6inch/
Digikey Bulk Order | 1 | Resisters, Headers, Capacitors | $52.50 | $52.50 | Digikey
Amazon Bulk Order | 1 | Standoffs | $2.50 | $2.50 | Amazon
Screwdriver | 1 | Sunex 11P1X3H Phillips Screwdriver #1 x 3" with Bolster | $3.52 | $3.52 | Amazon
Screwdriver | 1 | HARFINGTON PH00 Mini Phillips Screwdriver #00 3.1" | $0.29 | $0.29 | Amazon
Pi Battery | 1 | Powerbank Fast Charging Max 12V/4.5A | $15.99 | $15.99 | Amazon https://www.amazon.com/dp/B0F7L4D18S?ref=fed_asin_title&th=1
Rubber band | 1 | Size #27 | $0.01 | $0.01
Total Hardware BOM |  |  |  | $749.85
Soldering | 1 | Soldering custom electronics boards (paid out to students and interns) | $195.00 | $195.00
Shipping | 1 | Shipping / Tarrifs / Taxes Paid | $20.00 | $20.00
Credit Card Fees | 1 | Transaction fees | $33.77 | $33.77
Total Cost |  |  |  | $998.62

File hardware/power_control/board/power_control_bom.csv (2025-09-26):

Reference | Quantity | Value | Footprint | Digikey Part | MFG Part | Description | Datasheet
C1 C3 C4 | 3 | 2.2u | Capacitor_SMD:C_0603_1608Metric_Pad1.08x0.95mm_HandSolder |  |  |  | ~
C2 C5 | 2 | 100n | Capacitor_SMD:C_0603_1608Metric_Pad1.08x0.95mm_HandSolder |  |  |  | ~
J1 J2 | 2 | Conn_01x03 | Connector_PinHeader_2.54mm:PinHeader_1x03_P2.54mm_Vertical |  |  |  | ~
J3 | 1 | Conn_01x04 | Connector_PinHeader_2.54mm:PinHeader_1x04_P2.54mm_Vertical |  |  |  | ~
J4 | 1 | Conn_01x06 | Connector_PinHeader_2.54mm:PinHeader_1x06_P2.54mm_Vertical |  |  |  | ~
J5 | 1 | Conn_01x02 | Connector_PinHeader_2.54mm:PinHeader_1x02_P2.54mm_Vertical |  |  |  | ~
J6 | 1 |  | Package_TO_SOT_SMD:SOT-363_SC-70-6_Handsoldering | 1727-2733-1-ND | NX138BKSX | MOSFET 2 N-CH 60V 210MA 6TSSOP | ~
R1 | 1 | 330k | Resistor_SMD:R_0603_1608Metric_Pad0.98x0.95mm_HandSolder |  |  |  | ~
R2 | 1 | 1M | Resistor_SMD:R_0603_1608Metric_Pad0.98x0.95mm_HandSolder |  |  |  | ~
R3 | 1 | 4.7k | Resistor_SMD:R_0603_1608Metric_Pad0.98x0.95mm_HandSolder |  |  |  | ~
R5 | 1 | 1k | Resistor_SMD:R_0603_1608Metric_Pad0.98x0.95mm_HandSolder |  |  |  | ~
R7 R8 R9 R10 R11 | 5 | 10k | Resistor_SMD:R_0603_1608Metric_Pad0.98x0.95mm_HandSolder |  |  |  | ~
SW1 | 1 | SW_Push | Button_Switch_SMD:SW_SPST_TL3305A | EG5350CT-ND | TL3305AF160QG | SWITCH TACTILE SPST-NO 50MA 12V | ~
U1 | 1 | MCP1703A-5002_SOT23 | Package_TO_SOT_SMD:SOT-23 | MCP1792T-3302H/CBCT-ND | MCP1792T-3302H/CB | IC REG LIN 3.3V 100MA SOT23A-3 | http://ww1.microchip.com/downloads/en/DeviceDoc/20005122B.pdf
U2 | 1 | ATtiny1604-SS | Package_SO:SOIC-14_3.9x8.7mm_P1.27mm | ATTINY1604-SSNRCT-ND | ATTINY1604-SSNR | IC MCU 8BIT 16KB FLASH 14SOIC | http://ww1.microchip.com/downloads/en/DeviceDoc/ATtiny804_1604-Data-Sheet-40002028A.pdf

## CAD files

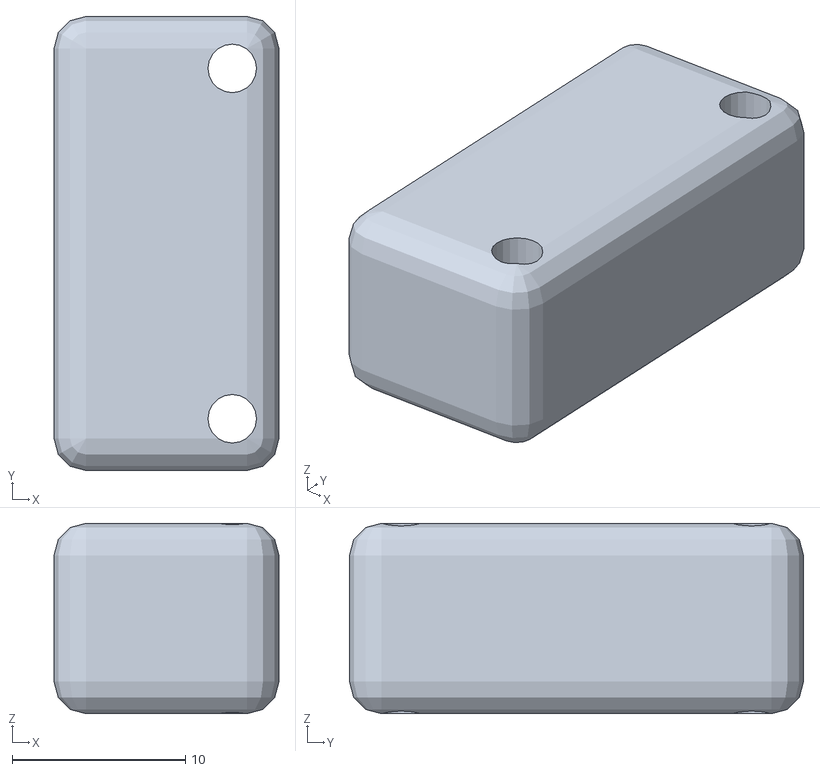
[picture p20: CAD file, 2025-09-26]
3dprint/Common_Robotics_IMU_Support.stl
13.0 x 26.2 x 11.0

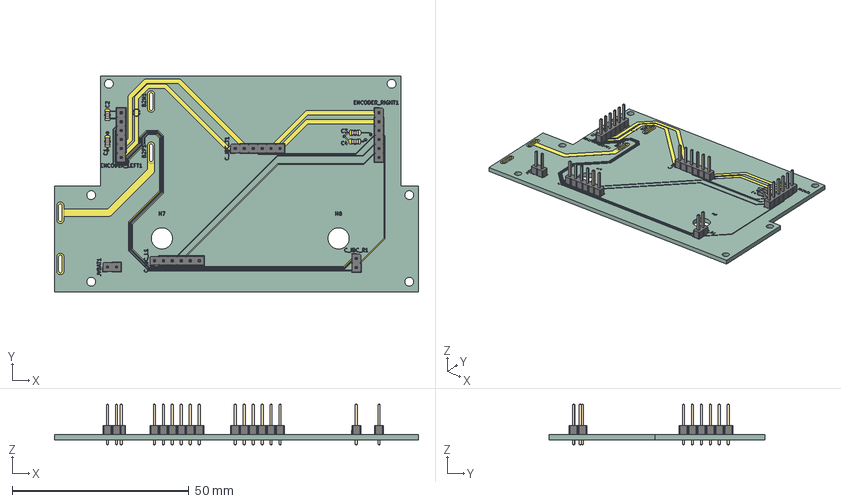
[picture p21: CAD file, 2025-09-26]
hardware/romi_board/romi_board_bottom.step
103.0 x 61.0 x 11.5 mm
PinHeader_1x06_P2.54mm_Vertical x 4
PinHeader_1x02_P2.54mm_Vertical x 2
C_0805_2012Metric x 4
romi_board_bottom_copper
romi_board_bottom_silkscreen
romi_board_bottom_PCB

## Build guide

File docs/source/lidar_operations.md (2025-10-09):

# LiDAR Operations

This guide covers LiDAR sensor operations, setup, and troubleshooting for the RCR Common Robotics Platform. The robot uses a  2-dimensional LiDAR sensor for obstacle detection, mapping, and navigation. The LiDAR provides 360-degree range measurements around the robot.

## Launch ROS Node

> ⚠️ **Important**: Ensure a ROS discovery server is running (see [Discovery Server Setup](../operations/discovery_server.md))

**Launch LiDAR:**
```bash
cd ~/repos/common_platform/common_platform_ws/
source install/setup.bash
ros2 launch sensors rplidar.launch.py
```

You will need to leave this window open for as long as you want the LiDAR running. If you want to verify that the LiDar data is streaming you can echo the topic, to do so open a new terminal window 📟

**Verify LiDAR Data:**
```bash
ros2 topic echo /${ROS_NAME}/scan
```
You should see a stream of data points here if your LiDAR is publishing data to ROS.

**Monitor data rate**
```bash
ros2 topic hz /${ROS_NAME}/scan
```

Once you have checked the data stream, you can close this window as this is just for testing and diagnosis. You want to get in the habit of looking for the ros topic to verify data is streaming. You can do this with:

**View all ROS topics**
 ```bash
 ros2 topic list
 ```

## LiDAR Data Analysis

**Scan Message:**
```yaml
std_msgs/Header header
float32 angle_min
float32 angle_max
float32 angle_increment
float32 time_increment
float32 scan_time
float32 range_min
float32 range_max
float32[] ranges
float32[] intensities
```

 Check for:
 - Consistent range values
 - No missing data points
 - Reasonable intensity values

**Diagnostic Commands**

```bash
# Check USB devices
lsusb | grep -i lidar

# Check serial devices
ls /dev/tty*

# Test serial communication
ros2 run rplidar_ros rplidar_node --ros-args -p serial_port:=/dev/ttyUSB0

# Monitor data quality
ros2 topic echo /${ROS_NAME}/scan
ros2 topic hz /${ROS_NAME}/scan
```

## Troubleshooting

**No LiDAR Data:**
- Check USB connection
- Verify Teensy is powered and running
- Ensure a discovery server is running
- Connect Cursor to your Pi via SSH and ask for diagnosis help

## Hardware Connection

1. **Physical Mounting**
   - Mount LiDAR on designated mounting point
   - Ensure clear 360° rotation
   - Secure mounting to prevent vibration

2. **Power Connection**
   - Connect power cable to robot power system
   - Verify voltage requirements (5V)
   - Check for proper grounding

3. **Data Connection**
   - Connect USB cable to robot controller
   - Verify serial communication
   - Test connection stability

## Calibration

### Mounting Calibration

**Check Mounting:**
- Verify LiDAR is level
- Ensure no obstructions
- Check for vibration

**Test Rotation:**
```bash
ros2 service call /${ROS_NAME}/stop_motor std_srvs/srv/Empty {}
ros2 service call /${ROS_NAME}/start_motor std_srvs/srv/Empty {}
```

### Range Calibration

**Test Range Accuracy:**
1. Place known objects at known distances
2. Compare LiDAR readings with actual distances
3. Adjust calibration if needed

**Verify Range Limits:**
- Test minimum range (0.15m)
- Test maximum range (12m)
- Check for blind spots

## LiDAR Specifications

- **Model**: RPLidar A1M8
- **Range**: 0.15m - 12m
- **Angular Resolution**: 0.33°
- **Scan Rate**: 5.5 Hz
- **Interface**: Serial (USB)

## Performance Optimization

### Data Processing

**Filtering:**
- Remove noise from data
- Filter out invalid readings
- Smooth data for better performance

**Downsampling:**
- Reduce data rate if needed
- Maintain sufficient resolution
- Balance performance vs. accuracy

### Parameter Tuning

**Scan Parameters:**
```yaml
# In launch file
scan_time: 0.1
range_min: 0.15
range_max: 12.0
```

**Update Rates:**
- Adjust scan frequency
- Balance performance vs. accuracy
- Consider computational load

---

*For camera operations, see [Camera Operations](../camera/camera_operations.md)*
*For IMU operations, see [IMU Operations](imu_operations.md)*
*For troubleshooting, see [Troubleshooting](../troubleshooting/index.md)*

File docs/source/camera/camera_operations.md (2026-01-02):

# Camera Operations

This guide covers camera operations, setup, and troubleshooting for the RCR Common Robotics Platform.

## Overview

The robot uses a camera for visual perception, navigation, and object detection. The camera provides real-time image data for various applications.

## Camera Specifications

- **Model**: USB Camera
- **Resolution**: 640x480 (configurable)
- **Frame Rate**: 30 FPS
- **Interface**: USB 2.0
- **Field of View**: 60° (approximate)

## Prerequisites

- **Discovery Server Running**: Ensure a ROS discovery server is running (see [Discovery Server Setup](../operations/discovery_server.md))
- Camera hardware properly connected
- ROS2 environment sourced
- Sufficient battery charge

## Camera Setup

### 1. Hardware Connection

1. **Physical Mounting**
   - Mount camera on designated mounting point
   - Ensure clear field of view
   - Secure mounting to prevent vibration

2. **Power Connection**
   - Connect USB cable to robot controller
   - Verify power requirements
   - Check for proper grounding

3. **Data Connection**
   - Connect USB cable to robot controller
   - Verify USB communication
   - Test connection stability

### 2. Software Configuration

Open a new terminal window 📟

**Launch Camera:**
```bash
# Launch camera node
cd ~/repos/common_platform/common_platform_ws
source install/setup.bash
ros2 launch sensors camera.launch.py
```

You will need to leave this window open for as long as you want the camera running. If you want to verify that the camera data is streaming you can echo the topic, to do so open a new terminal window 📟

**Check camera data stream:**
```bash
ros2 topic echo /${ROS_NAME}/camera/image_raw
```
**Monitor data rate (in hertz):**
```bash
ros2 topic hz /${ROS_NAME}/camera/image_raw
```

Once you have checked the data stream, you can close this window as this is just for testing and diagnosis. You want to get in the habit of looking for the ros topic to verify data is streaming. You can do this with:

**View all ROS topics**
 ```bash
 ros2 topic list
 ```

## Camera Applications

### Computer Vision
In order to collect images to annotate in Label Studio, use our custom data_recorder node. This is the first step in fine tuning an existing neural network. Check the [Data Annotation](../data_annotation/label_studio.md) document for information on labeling.

## Recording Image Files
Open a new terminal window 📟.

If you have never recorded images before, you will need to first build the data-recorder package. After running this once you should not need to do it again in the future.

```bash
cd ~/repos/common_platform/common_platform_ws/
colcon build --packages-select data_recorder
```

**Launch recorder**
```bash
source install/setup.bash
ros2 launch data_recorder ramdisk_recorder.launch.py
```

Recording images will fill up your RAM on your Pi relatively quickly - keep it to about 1-2 minutes total of image capture before annotating your data.

**Stop recorder**
The **recorder needs to be stopped manually using `Ctrl+C`**. It should automatically copy the recorded frames from the RAM disk to the following location on your micro SD card: ~/teleop_data/ . Check for a folder called session_<DATE>_<TIME> .

Now go check your ~/teleop_data/session_YYYY-MM-DD_HH-MM-SS/images folder
>  Replace session_YYYY-MM-DD_HH-MM-SS with the actual session folder name and you should see some images in there.

**Next step:** Annotating your data with [Label Studio](../data_annotation/label_studio.md)

## Recording Video Files

Open a new terminal window 📟

```bash
ros2 run image_view video_recorder --ros-args -p filename:=/tmp/robot_video.avi
```

The video file will be saved to /tmp/robot_video.avi on your Raspberry Pi.

---

### Visual Navigation

**Feature Detection:**
- Detect visual features
- Use for localization
- Implement visual SLAM

**Object Recognition:**
- Identify objects
- Navigate to targets
- Avoid obstacles

### Real-time Monitoring
```bash
# View camera feed - you need a virtual environment running to do this - more details soon but in the meantime run this on Joe's computer.
ros2 run rqt_image_view rqt_image_view
```

## Camera Calibration

### 1. Intrinsic Calibration

**Calibration Process:**
1. Print calibration pattern
2. Launch camera
3. Run calibration tool
4. Save calibration parameters

**Calibration Command:**
```bash
# Run camera calibration
# Command to be added after verification
```

### 2. Extrinsic Calibration

**Coordinate Frame Alignment:**
- Align camera with robot frame
- Verify coordinate transformations
- Test with known objects

**Transform Setup:**
```bash
# Check transform tree
ros2 run tf2_tools view_frames

# Verify camera transform
ros2 run tf2_ros tf2_echo base_link camera_link
```

## Camera Data Analysis

### 1. Image Data

**Image Message:**
```yaml
std_msgs/Header header
uint32 height
uint32 width
string encoding
uint8 is_bigendian
uint32 step
uint8[] data
```

### 2. Data Quality

**Check Image Quality:**
```bash
# View camera feed
ros2 run rqt_image_view rqt_image_view

# Check for:
# - Clear image
# - Proper exposure
# - No distortion
# - Consistent frame rate
```

## Troubleshooting

### Common Issues

Check the camera hardware is present
```bash
cam -l
```

**No Camera Data:**
- Check USB connection
- Verify Teensy is powered and running
- Ensure a discovery server is running
- Connect Cursor to your Pi via SSH and ask for diagnosis help

**Poor Image Quality:**
- Clean camera lens
- Check for obstructions
- Verify focus
- Test in different lighting

**Inconsistent Frame Rate:**
- Check USB bandwidth
- Verify power supply
- Test with different resolution
- Check for interference

### Diagnostic Commands

```bash
# Check USB devices
lsusb | grep -i camera

# Check video devices
ls /dev/video*

# Test camera
ros2 run usb_cam usb_cam_node --ros-args -p video_device:=/dev/video0

# Monitor data quality
ros2 topic echo /${ROS_NAME}/camera/image_raw
ros2 topic hz /${ROS_NAME}/camera/image_raw
```

### Error Codes

**Common Error Messages:**
- "Failed to open video device" - Check USB connection
- "No frames received" - Check power and connections
- "Invalid image data" - Check for interference or damage

## Maintenance

### Regular Maintenance
- Visual inspection
- Check for obstructions
- Verify image quality
- Clean camera lens
- Check mounting stability
- Test focus

### Cleaning Procedures

**Camera Lens:**
1. Power off robot
2. Use soft, lint-free cloth
3. Clean gently to avoid scratches
4. Remove dust and debris
5. Verify clear view

**Mounting Area:**
- Clean mounting surface
- Check for loose connections
- Verify stability

## Performance Optimization

### Image Processing

**Resolution:**
- Adjust resolution for performance
- Balance quality vs. speed
- Consider bandwidth requirements

**Frame Rate:**
- Adjust frame rate as needed
- Balance performance vs. accuracy
- Consider computational load

### Parameter Tuning

**Camera Parameters:**
```yaml
# In launch file
image_width: 640
image_height: 480
framerate: 30
```

**Processing Parameters:**
- Adjust processing algorithms
- Optimize for real-time performance
- Balance accuracy vs. speed
---

*For LiDAR operations, see [LiDAR Operations](../lidar_operations.md)*
*For IMU operations, see [IMU Operations](../operations/sensors/imu_operations.md)*
*For troubleshooting, see [Troubleshooting](../operations/troubleshooting/index.md)*

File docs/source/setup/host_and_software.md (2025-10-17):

# Host and Network Setup

This section covers the complete setup process for the common platform robot, including host configuration, software installation, and firmware programming.

## Pull the Latest Changes from GitHub

Change to the correct git-enabled directory:

```bash
cd repos/common_platform
```

Stash any changes you have made:

```bash
git stash
```

Update the Git remote for the public repo so you don't need credentials. You should only need to do this step once.

```bash
git remote set-url origin "https://github.com/RoseCityRobotics/common_platform.git"
```

Pull the changes

```bash
git pull origin main
```

Re-apply your stashed changes

```bash
git stash apply
```

## Host Settings
Raspberry Pi
The host has been preset for you as `rcr00n` with your specific ID in place of "n". To update the hostname:

1. Tell cloud-init to preserve your hostname:
   ```bash
   sudo nano /etc/cloud/cloud.cfg
   ```
   Set `preserve_hostname: true` and save the file

2. Update the hostname for the robot:
   ```bash
   sudo nano /etc/hostname
   ```
   Change `rcr001` to `rcr00n` (replace n with the number)

3. Update the hosts file:
   ```bash
   sudo nano /etc/hosts
   ```
   Change `rcr001` to `rcr00n`

4. Set the hostname:
   ```bash
   sudo hostnamectl set-hostname rcr00n
   ```

5. Reboot to make sure the changes have taken effect:
   ```bash
   sudo reboot
   ```

## Network Configuration
Raspberry Pi

In this section we will set a custom IP address, set up networking and add WiFi access points. The Pi will try access points in order from top to bottom until it is successful connecting.

Edit the netplan configuration:
```bash
sudo nano /etc/netplan/50-cloud-init.yaml
```

Add the following configuration (replace `n` with your robot number):
```yaml
network:
  version: 2
  wifis:
    wlan0:
      optional: true
      dhcp4: no
      addresses:
        - 192.168.1.n/24
      routes:
        - to: default
          via: 192.168.1.1
      nameservers:
        addresses: [8.8.8.8, 1.1.1.1]
      access-points:
        "robot_overlord_wifi":
          password: "siliconforest"
        "RoseCityRobotics":
          password: "QW260go80.."
```
**Note:** `n` = the robot number. Add your home WiFi access point as well.

Apply the network configuration:
```bash
sudo netplan apply
```

## SSH Connection
**🖥️ On the development computer:** Connect via SSH:
```bash
ssh rcr@192.168.1.n
```
Replace `n` with your robot number.

### Accessing the Pi from your development machine via SSH
Raspberry Pi 🖥️
Both the external device and the robot must be on the same WiFi for SSH to work. Use the static IP address of your Pi to SSH. The command will look something like `ssh rcr@192.168.1.n` where `n` is your ID, for example `ssh rcr@192.168.1.9`.

### Troubleshooting SSH Connections
**Raspberry Pi On the Pi:** Make sure the IP address is assigned:
```bash
hostname -I
```

Check the host name
```bash
hostname
```

Ping a website to verify network connectivity
```bash
ping google.com
```

Make sure your development machine 🖥️ is on the same network.

## Robot Namespacing Setup

Since we are running a swarm of many robots we need the ROS nodes and topics to be namespaced. To ensure your robot runs under its unique namespace (e.g., `/rcr001`, `/rcr002`, etc.), follow these steps:

### Set Your Namespace in `.profile`

Edit your shell profile to define your robot's namespace:

```bash
sudo nano ~/.profile
```

Add or update this line (replace `n` with your robot number):

```bash
export ROS_NAME=rcr00n
```

Save and close the file, then reload your profile:

```bash
source ~/.profile
```

This ensures that your environment variables are set on login and immediately available in your current session.

---

### Set Namespace in `env.list`

Update the environment variable file used for Docker and ROS:

```bash
sudo nano ~/env.list
```

Add or update the line:

```bash
ROS_NAMESPACE=/rcr00n
```

---

### Set Firmware Namespace

In your firmware directory, update the namespace inside the `ros_interface.cpp` file:

```bash
cd ~/repos/common_platform/firmware/closed_loop/
sudo nano RosInterface.cpp
```

Find this line where the node is initialized with a namespace (default should either be empty `""` or `rcr001`). Change it to `rcr00n`:

```cpp
rclc_node_init_default(&node, "micro_ros_arduino_node", "rcr00n", &support));
```

This sets the micro-ROS node namespace properly for communication with ROS2.

### Reload the Firmware
⚠️ **Important:** After updating this firmware, you must re-flash the Teensy. For detailed instructions on flashing the Teensy firmware, see the [Teensy Programming Guide](teensy_programming.md).

<p align="right">(<a href="#readme-top">back to top</a>)</p>

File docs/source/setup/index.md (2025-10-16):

# Host and Software Setup

This section covers the complete setup process for the common platform robot, including host configuration, software installation, and firmware programming.

## Setup Steps

```{toctree}
:maxdepth: 1

pi_connection
host_and_software
teensy_programming
```

### Quick Reference

- **[Pi Connection](pi_connection.md)** - Connect to your robot's Raspberry Pi via direct connection or SSH
- **[Host Configuration](host_and_software)** - Set up your robot's hostname, network, and SSH access
- **[Firmware Programming](teensy_programming.md)** - Flash the Teensy with the latest firmware
- **[Verification](host_and_software)** - Test all systems before proceeding with operations

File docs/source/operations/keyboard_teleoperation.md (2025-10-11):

# Keyboard Teleoperation

This document outlines essential commands for setting up a ROS2 environment, particularly focusing on micro-ROS integration with a Teensy microcontroller and keyboard teleoperation.

-----

## Prerequisites

Before starting keyboard teleoperation, ensure you have:

1. **Discovery Server Running**: See [Discovery Server Setup](discovery_server.md) for setup instructions
2. **Robot Powered On**: Ensure your both the Pi and Teensy are powered and connected
3. **Network Connectivity**: Verify connection between your computer and the robot

-----

## Power and Log on to Raspberry Pi

The Raspberry Pi will host the micro-ROS agent and other ROS2 nodes. Ensure it's powered on and you're logged in. Required ROS2 environment variables set in the [**`.profile`**](https://github.com/RoseCityRobotics/common_platform/blob/main/.profile) file for automated setup upon login.

You will need a separate terminal window 📟 for each process below:

## Setup a terminal with miniterm to monitor Teensy debug output

Open a new terminal window 📟

**Get your Teensy serial number**
```bash
SERIAL_NUM=$(
basename "$(find /dev/serial/by-id/ -name 'usb-Teensyduino*if0[02]' | head -1)" \
| sed -E 's/.*_([0-9A-Za-z]+)-if0[02]/\1/'
)
echo "Teensy serial: $SERIAL_NUM"
```

**Start Miniterm**
```bash
python3 -m serial.tools.miniterm "/dev/serial/by-id/usb-Teensyduino_Dual_Serial_${SERIAL_NUM}-if02" 115200

```

This command starts a `miniterm` session to display debug messages from the Teensy. The path identifies your Teensy and the {SERIAL_NUM} command pulls your serial number, and `115200` sets the baud rate. You should expect to see "**WAITING\_AGENT**" if the Teensy is awaiting a connection.

## Start the micro-ROS Agent

Open a new terminal window 📟

The micro-ROS agent acts as a bridge between the micro-ROS client running on the Teensy and the ROS2 network.

**Get your Teensy serial number** (you have to do this again since its a new window)
```bash
SERIAL_NUM=$(
basename "$(find /dev/serial/by-id/ -name 'usb-Teensyduino*if0[02]' | head -1)" \
| sed -E 's/.*_([0-9A-Za-z]+)-if0[02]/\1/'
)
echo "Teensy serial: $SERIAL_NUM"
```

```bash
cd ~
sudo docker run -it --rm \
  -v /dev:/dev --privileged --net=host \
  --env-file ./env.list --name agent\
  microros/micro-ros-agent:kilted \
  serial --dev "/dev/serial/by-id/usb-Teensyduino_Dual_Serial_${SERIAL_NUM}-if00" -v4
```

This Docker command starts the micro-ROS agent:

  * **`sudo docker run`**: Executes a Docker container.
  * **`-it`**: Runs in interactive mode with a pseudo-TTY.
  * **`--rm`**: Automatically removes the container when it exits.
  * **`-v /dev:/dev`**: Mounts the host's `/dev` directory into the container, allowing access to serial devices.
  * **`--privileged`**: Grants the container elevated privileges, necessary for direct hardware access.
  * **`--net=host`**: Uses the host's network stack, simplifying network configuration.
  * **`--env-file ./env.list`**: Loads environment variables from the `env.list` file.
  * **`microros/micro-ros-agent:kilted`**: Specifies the Docker image to use.
  * **`serial --dev ...`**: Instructs the agent to connect via a serial port, specifying the Teensy's serial device path.
  * **`-v4`**: Sets the verbosity level for the agent's output.

## Start the Keyboard Monitor Node

Open a new terminal window 📟

This node allows you to control your robot or application using keyboard inputs.

```bash
cd ~/repos/common_platform/common_platform_ws
source install/setup.bash
ros2 launch evdev_teleop evdev_teleop.launch.py
```

This command launches the `evdev_teleop` package, which sets up a ROS2 node to read keyboard input and publish corresponding control commands.

## Keyboard Commands 🎮

> ⚠️ **Important:** Put your robot on the ground before starting teleoperation!

| Command | Key | Action |
|---|-----|---|
| ⬆️ | **Forward Arrow** | Move forward |
| ⬇️ | **Backward Arrow** | Move backward |
| ⬅️ | **Left Arrow** | Turn left |
| ➡️ | **Right Arrow** | Turn right |
| ⏸️ | **Spacebar** | Stop/Emergency brake |

-----

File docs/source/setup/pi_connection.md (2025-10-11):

# Raspberry Pi Connection Guide

This guide covers how to connect to your robot's Raspberry Pi for development and operation.

## Direct Connection (Initial Setup)

**Hardware Required:**
- Micro HDMI cable
- USB keyboard
- Monitor with HDMI input
- Power supply for the robot

**Steps:**
- Connect the micro HDMI cable from the Raspberry Pi to your monitor
- Connect a USB keyboard to the Raspberry Pi's USB-A port
- Power on the robot
- Wait for the system to boot

**Login Credentials:**
- **Username:** `rcr`
- **Password:** `siliconforest`

## SSH Connection (Development)

**Prerequisites:**
- Robot and development computer on the same network
- SSH client installed on your development computer

**Connection Steps:**

Raspberry Pi on the Raspberry Pi

**Find your robot's IP address:**
  ```bash
  # From the robot's direct connection, check IP
  ip addr show
  ```

🖥️ On your development computer open a new terminal window 📟

**Connect via SSH:**
  ```bash
  ssh rcr@192.168.1.n
  ```
  Replace `n` with your robot's assigned number.

**Alternative connection if IP is known:**
  ```bash
  ssh rcr@<robot_ip_address>
  ```

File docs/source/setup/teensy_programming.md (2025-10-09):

# Teensy Programming - Use Arduino CLI
Raspberry Pi

**What we're doing:** We'll set up the Arduino CLI tool on the Raspberry Pi to compile and upload firmware to the Teensy microcontroller. This allows us to program the robot's brain (Teensy) directly from the command line without needing a graphical interface.

**Why Arduino CLI:** The Arduino CLI is the official command-line tool that provides all the functionality of the Arduino IDE but runs entirely in the terminal. This is perfect for our setup since we're working remotely via SSH on the Raspberry Pi.

Arduino provides an official `arduino-cli` tool. You can compile and upload Arduino code for a Teensy entirely from the Ubuntu command line. You will do this from the Raspberry Pi (after connecting via SSH).

#### 1. **Install Arduino CLI:**
```bash
curl -fsSL https://raw.githubusercontent.com/arduino/arduino-cli/master/install.sh | sh
mv bin/arduino-cli ~/.local/bin/
```

#### 2. **Configure Arduino CLI:**
```bash
arduino-cli config init
```

#### 3. **Add Teensy board support:**
```bash
arduino-cli core update-index
arduino-cli core install teensy:avr --additional-urls https://www.pjrc.com/teensy/package_teensy_index.json
```

#### 4. Transfer micro-ROS Arduino Library to Raspberry Pi

The required micro-ROS Arduino library is available in the repository: `firmware/libraries/micro_ros_arduino.zip` so we will  pull the repository to Raspberry Pi Raspberry Pi to access the file.

**What we're doing:** We need to transfer the micro-ROS library GitHub to the Raspberry Pi that's connected to your robot. The Raspberry Pi serves as the main computer that will compile and upload firmware to the Teensy microcontroller.

🖥️ From your development machine
```bash
ssh rcr@192.168.1.n
cd ~/repos/common_platform/
```

**Raspberry Pi From your Raspberry Pi** in the common_platform directory:

First update your directory with the latest changes from the https://github.com/roseCityRobotics/common_platform repository including the .zip file you'll need next.
```bash
git checkout main
git pull origin main
```

#### 5. Setup micro-ROS Library and Compile Firmware

**What we're doing:** Now we're working directly on the Raspberry Pi to set up the micro-ROS library and compile the robot's firmware. The Raspberry Pi will handle the compilation process and then upload the compiled code to the Teensy microcontroller.

**Raspberry Pi From the Raspberry Pi (RPi):**

a. Set up Arduino libraries directory:
   ```bash
   cd ~
   mkdir -p Arduino/libraries/
   cp repos/common_platform/firmware/libraries/micro_ros_arduino.zip Arduino/libraries/
   cd ~/Arduino/libraries/
   ```

b. Install unzip and extract the micro-ROS library:
   ```bash
   sudo apt update
   sudo apt install unzip
   unzip micro_ros_arduino.zip
   ```

c. Navigate to the common_platform repository, update it, and place the arduino-cli config files in the correct place
  ```bash
  cd ~/repos/common_platform/
  git checkout main
  git pull origin main
  scripts/place_arduino-cli_config.sh
  ```

## Next Steps

Now that you have the Arduino CLI configured and the micro-ROS library installed, you're ready to flash firmware to the Teensy microcontroller.

**Next: [Flashing the Teensy Microcontroller](../operations/advanced/firmware_updates.md)** - Complete guide for flashing firmware to the Teensy 4.0

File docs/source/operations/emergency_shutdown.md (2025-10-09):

# Emergency Shutdown

Emergency procedures for the RCR Common Robotics Platform when immediate shutdown is required.

## When to Use Emergency Shutdown

Use emergency shutdown procedures when:
- Battery overheating or smoking
- Fire or smoke from batteries
- System malfunction requiring immediate power cut
- Safety hazard requiring instant shutdown

## Emergency Shutdown Steps

### 1. Immediate Power Cut
```bash
# Kill all processes immediately
Ctrl+C (in all terminal windows)

# Force shutdown if system is unresponsive
sudo shutdown -h now
```

### 2. Physical Power Disconnect
- Turn off Teensy power switch immediately
- Remove Pi battery if safe to do so
- Remove Teensy battery if safe to do so
- Disconnect any external power sources

## ⚠️ LITHIUM-ION BATTERY SAFETY

**If you notice heat, smoke, or fire from the batteries:**

### Immediate Actions
1. **Turn off all power switches immediately**
2. **Remove batteries if safe to do so (wear protective gloves)**
3. **Move robot to a safe outdoor location if possible**

### Lithium Fire Safety
- **DO NOT** use water on lithium fires
- Lithium fires need to burn out completely
- Use a Class D fire extinguisher if available
- If fire starts, move robot outside and let it burn out safely
- Call emergency services (911) if needed

### After Emergency
- Do not attempt to recharge damaged batteries
- Dispose of damaged batteries properly at a hazardous waste facility
- Report the incident immediately

### Battery Safety Best Practices

**Always follow these safety guidelines:**

- **Keep batteries in chargers when not in use** - Never leave batteries installed in the robot when connected to external power
- **Remove batteries during charging** - Only charge batteries in designated charging stations, not while installed in the robot
- **Monitor charging process** - Never leave batteries charging unattended
- **Use proper storage** - Store batteries in a cool, dry location away from direct sunlight

## Normal Shutdown vs Emergency

**Normal Shutdown**: Use [Shutdown Procedure](shutdown_procedure.md) for routine shutdowns
**Emergency Shutdown**: Use this procedure only when immediate shutdown is required for safety

---

*For normal shutdown procedures, see [Shutdown Procedure](shutdown_procedure.md)*
*For startup procedures, see [Startup Procedure](startup_procedure.md)*
*For troubleshooting, see [Troubleshooting](../troubleshooting/index.md)*

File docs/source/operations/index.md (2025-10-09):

# Robot Operations Manual

Welcome to the Robot Operations Manual for the RCR Common Robotics Platform. This section contains detailed instructions for operating, maintaining, and troubleshooting your robot.

> 🔗 **GitHub Repository**: [https://github.com/RoseCityRobotics/common_platform](https://github.com/RoseCityRobotics/common_platform) - Source code and issue tracking

## Key Operations

```{toctree}
:maxdepth: 1

keyboard_teleoperation
ros2_joystick
startup_procedure
shutdown_procedure
maintenance
```

## Navigation Operations

```{toctree}
:maxdepth: 1

navigation/index
```

## Sensor Operations

```{toctree}
:maxdepth: 1

sensors/index
sensors/lidar_operations
sensors/imu_operations
```

## Setup and Configuration

```{toctree}
:maxdepth: 1

setup/index
setup/hardware_setup
setup/software_setup
setup/calibration
```

## Troubleshooting

```{toctree}
:maxdepth: 1

troubleshooting/index
troubleshooting/common_issues
troubleshooting/error_codes
troubleshooting/recovery_procedures
```

## Advanced Operations

```{toctree}
:maxdepth: 1

advanced/index
advanced/custom_controllers
advanced/firmware_updates
advanced/performance_tuning
discovery_server
```

## Safety Guidelines

⚠️ **IMPORTANT SAFETY NOTICE**: Always follow these safety guidelines when operating the robot:

1. **Power Safety**: Ensure proper power connections and never exceed voltage limits
2. **Environment**: Operate in a safe, controlled environment free of obstacles
3. **Emergency Stop**: Know the location and operation of emergency stop mechanisms
4. **Maintenance**: Perform regular maintenance as outlined in the maintenance procedures
5. **Updates**: Keep software and firmware updated for optimal performance and security

## Getting Help

If you encounter issues not covered in this manual:

1. Check the [Troubleshooting](troubleshooting/index.md) section first
2. Review the [Common Issues](troubleshooting/common_issues.md) page
3. Consult the main project documentation for technical details
4. Contact the PARTS team for additional support

## Contributing to Operations Documentation

To improve these operation instructions:

1. Document any new procedures you discover
2. Update existing procedures with improvements
3. Report issues or unclear instructions
4. Share your experiences with the community

---

*Last updated: [Current Date]*
*Version: 1.0*

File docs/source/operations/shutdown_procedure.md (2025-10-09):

# Shutdown Procedure

Simple shutdown procedure for the RCR Common Robotics Platform.

## Stop Software
```bash
# Kill all running processes
Ctrl+C
```

## Shutdown Raspberry Pi
```bash
sudo shutdown now
```

This command will safely power down the Raspberry Pi and all connected systems.

> 💡 **Tip:** Always use the proper shutdown command to avoid data corruption and ensure the system starts cleanly next time.

## Turn Off Hardware
- Turn off Teensy power switch
- Remove Pi battery
- Remove Teensy battery

## Recharge Batteries
- Recharge both Pi and Teensy batteries
- Store in designated charging area

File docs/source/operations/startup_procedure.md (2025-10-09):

# Startup Procedure

This document outlines the proper procedure for starting up your RCR Common Robotics Platform.

## Pre-Startup Checklist

Before starting the robot, verify:

- [ ] Battery is charged
- [ ] All connections are secure
- [ ] Robot is in a safe operating environment
- [ ] Emergency stop is accessible
- [ ] No obstacles in immediate area

## Power On
- Add batteries to Teensy
- Connect Pi Battery
- Turn on main Teensy power switch
- Verify Teensy and Pi power LED indicators are on

## System Initialization

**Controller Boot**
   - Wait for controller to complete boot sequence
   - Verify boot messages on console (if available)
   - Check for any error messages

**Sensor Initialization**
   - LiDAR should begin spinning
   - Camera should initialize
   - IMU should calibrate automatically

## Software Launch

**ROS2 Launch**
   ```bash
   # Launch the main robot system
   ros2 launch common_platform launch_robot.launch.py
   ```

Open a new terminal window 📟

**Verify Topics**
   ```bash
   # Check that all expected topics are publishing
   ros2 topic list
   ```

**Check Node Status**
   ```bash
   # Verify all nodes are running
   ros2 node list
   ```

## System Verification

 **Sensor Data**
   - Verify LiDAR data is being published
   - Check camera feed
   - Confirm IMU data is available

 **Motor System**
   - Test motor responsiveness
   - Verify encoder data
   - Check for any unusual sounds

 **Navigation System**
   - Confirm localization is working
   - Check map loading (if applicable)
   - Verify path planning capabilities

## Expected Startup Time

- **Hardware initialization**: 10-15 seconds
- **Software launch**: 30-60 seconds
- **Full system ready**: 1-2 minutes

## Troubleshooting Startup Issues

### Common Problems

**Battery Check**
   ```bash
   # Check battery voltage (should be >9V)
   # Connect multimeter to battery terminals
   ```

**Discovery Server Running**
   - Ensure a ROS discovery server is running before starting robot operations
   - See [Discovery Server Setup](discovery_server.md) for detailed setup instructions
   - If at Rose City Robotics Lab, a discovery server is already running on the network

---

*For shutdown procedures, see [Shutdown Procedure](shutdown_procedure.md)*
*For troubleshooting, see [Troubleshooting](../troubleshooting/index.md)*

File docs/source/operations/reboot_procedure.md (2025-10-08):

# Reboot Procedure
```bash
sudo reboot
```

The downside of running this command is you will need to restart all of the processes you have running in other windows. That being said as a sledgehammer approach, power cycling both the Pi and the Teensy can be a good troubleshooting step to try.

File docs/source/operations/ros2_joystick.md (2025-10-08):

Of course\! Here is an expanded and nicely formatted markdown version of the text you provided.

# Using a Bluetooth Gamepad

This guide walks you through configuring a standard Bluetooth (BT) gamepad to control a ROS2-based robot. The process involves creating a custom ROS2 package to launch and configure the necessary nodes that translate your joystick movements into robot motion commands.

-----

## 🧐 Prerequisites & Setup

Before diving into ROS2, you need to ensure your system is ready.

1.  **Pair the Gamepad**: First, you must pair your Bluetooth gamepad with the Raspberry Pi's operating system. Use the standard Bluetooth graphical interface or command-line tools like `bluetoothctl` to scan for and connect your device.

2.  **Install ROS2 Packages**: You'll need two key packages to get this working. If they aren't already installed in your ROS2 environment (e.g., your Docker container), install them now:

    ```bash
    # Replace ${ROS_DISTRO} with your ROS2 version (e.g. kilted) in case the ROS_DISTRO environment variable is not set
    sudo apt update
    sudo apt install ros-${ROS_DISTRO}-joy ros-${ROS_DISTRO}-teleop-twist-joy
    ```

      * **`joy`**: This package contains the `joy_node`, which connects to your gamepad device (`/dev/input/js0`, for example) and publishes its raw button presses and axis states to a ROS2 topic called `/joy`.
      * **`teleop_twist_joy`**: This package provides the `teleop_node`, which listens to the `/joy` topic and converts the raw joystick data into standard `Twist` messages on the `/cmd_vel` topic, which is what most robot drivers use to control movement.

-----

## 🛠️ Creating the Teleop Package

To keep our configuration organized, we'll create a dedicated ROS2 package.

### 1\. Create a ROS2 Workspace

If you don't already have one, create a new ROS2 workspace. This is the standard directory for developing your own packages.

```bash
# Create the directory structure
mkdir -p ~/ros2_ws/src
cd ~/ros2_ws
```

### 2\. Create the New Package

Now, create a new package named `common_robot` inside the `src` directory.

```bash
cd ~/ros2_ws/src
ros2 pkg create --build-type ament_cmake common_robot
```

### 3\. Create `launch` and `config` Directories

Inside your new package, create subdirectories to hold your launch file and configuration file. This is a common and recommended practice.

```bash
cd common_robot
mkdir launch
mkdir config
```

-----

## ⚙️ Configuration Files

Now, let's create the two files that will define and configure our teleoperation setup.

### 1\. The Launch File (`joystick.launch.py`)

A launch file allows you to start and configure multiple ROS2 nodes with a single command. Inside the `common_robot/launch` directory, create a new file named `joystick.launch.py` and add the following Python code.

```python
# ~/ros2_ws/src/common_robot/launch/joystick.launch.py

from launch import LaunchDescription
from launch_ros.actions import Node
import os
from ament_index_python.packages import get_package_share_directory

def generate_launch_description():
    # Define the path to the joystick configuration file
    joy_params = os.path.join(
        get_package_share_directory('common_robot'),
        'config',
        'joystick.yaml'
    )

    # Node to handle joystick input
    joy_node = Node(
            package='joy',
            executable='joy_node',
            parameters=[joy_params],
         )

    # Node to convert joystick commands to robot motion (Twist messages)
    teleop_node = Node(
        package='teleop_twist_joy',
        executable='teleop_node',
        name='teleop_node',
        parameters=[joy_params],
        # Uncomment the following line to remap the output topic if your robot
        # expects velocity commands on a different topic name
        # remappings=[('/cmd_vel', '/diff_cont/cmd_vel_unstamped')]
    )

    return LaunchDescription([
        joy_node,
        teleop_node
    ])
```

**What this file does:**

  * It defines a path to a YAML configuration file (`joystick.yaml`).
  * It declares a `joy_node` that will read data from your gamepad.
  * It declares a `teleop_node` that will convert the gamepad data into velocity commands.
  * Crucially, it passes the `joy_params` file to **both** nodes, so they share the same configuration.

### 2\. The YAML Config File (`joystick.yaml`)

This file contains all the specific parameters for your gamepad, like which stick controls forward motion and how fast the robot should go. Inside the `common_robot/config` directory, create a file named `joystick.yaml` with the following content.

```yaml
# ~/ros2_ws/src/common_robot/config/joystick.yaml

joy_node:
  ros__parameters:
    device_id: 0         # Corresponds to /dev/input/js0
    deadzone: 0.05       # Ignores small stick movements
    autorepeat_rate: 20.0  # Rate (in Hz) to publish joy messages

teleop_node:
  ros__parameters:
    # Axis mappings for linear (forward/backward) and angular (turning) motion
    axis_linear:
      x: 1  # Vertical axis of the left thumb stick
    scale_linear:
      x: 0.4 # Max linear speed (m/s)
    scale_linear_turbo:
      x: 0.8 # Max linear speed when turbo button is pressed

    axis_angular:
      yaw: 0 # Horizontal axis of the left thumb stick
    scale_angular:
      yaw: 0.5 # Max angular speed (rad/s)
    scale_angular_turbo:
      yaw: 1.0 # Max angular speed when turbo button is pressed

    # Button mappings
    require_enable_button: true   # If true, a button must be held to move the robot (safety feature)
    enable_button: 4              # Left bumper (LB) button
    enable_turbo_button: 5        # Right bumper (RB) button
```

**Understanding these parameters:**

  * `device_id`: The system ID of your joystick. `0` usually corresponds to `/dev/input/js0`.
  * `deadzone`: The amount you need to move the stick from the center before it registers a command. This prevents "drift" from a worn-out stick.
  * `axis_linear`/`axis_angular`: These map a specific joystick axis number to a type of motion. You may need to change these values for your specific gamepad\!
  * `scale_linear`/`scale_angular`: These control the maximum speed of the robot.
  * `enable_button`: This acts as a "dead man's switch." The robot will only move while this button is held down. This is a highly recommended safety feature.
  * `enable_turbo_button`: Allows you to move faster by holding down a second button.

> **💡 Pro Tip:** To find the correct axis and button numbers for your controller, you can use a tool like `jstest-gtk` or simply watch the output of `ros2 run joy joy_node` in a separate terminal while you press buttons.

-----

## 🚀 Building and Running

Finally, let's build the package and launch it.

### 1\. Edit `CMakeLists.txt`

You must tell ROS2 to install your `launch` and `config` directories so it can find your files. Open the `CMakeLists.txt` file in your `common_robot` package and add the following lines just before the final `ament_package()` call.

```cmake
# Install launch files
install(DIRECTORY launch
  DESTINATION share/${PROJECT_NAME}
)

# Install config files
install(DIRECTORY config
  DESTINATION share/${PROJECT_NAME}
)
```

### 2\. Build and Source the Workspace

Navigate back to the root of your workspace (`~/ros2_ws`), build your new package, and then source the setup file to make your terminal aware of it.

```bash
cd ~/ros2_ws

# Build all packages in the workspace
colcon build --symlink-install

# Source the setup file to update your environment
source install/setup.bash
```

**Note:** You must `source` the setup file in **every new terminal** where you want to use your package's nodes or launch files.

### 3\. Run Teleop\!

You're all set\! Launch the file you created. Make sure your gamepad is on and connected.

```bash
ros2 launch common_robot joystick.launch.py
```

Now, while holding down your enable button (the left bumper in the config above), move the left thumbstick. Your robot should move\! Press the turbo button (right bumper) to go faster.

### 4\. Verification

To see if it's working, open a **new terminal** (and remember to source `install/setup.bash` again) and use the following command to watch the velocity commands being published:

```bash
ros2 topic echo /${ROS_NAME}/cmd_vel
```

You should see messages appear as you move the joystick.

-----

## 📚 Resources

For more details on the concepts used here, this is an excellent resource:

  * [Articulated Robotics: ROS2 C++ Mobile Robot Teleop](https://articulatedrobotics.xyz/mobile-robot-14a-teleop/)

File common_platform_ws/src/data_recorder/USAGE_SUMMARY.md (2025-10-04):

# Data Recorder Usage Summary

## 🚀 **Quick Start Commands**

### **Standard Recording (SD Card)**
```bash
# Start recording
ros2 launch data_recorder data_recorder_with_camera.launch.py

# Control recording
python3 install/data_recorder/lib/data_recorder/record_control.py start
python3 install/data_recorder/lib/data_recorder/record_control.py stop
python3 install/data_recorder/lib/data_recorder/record_control.py status
```

### **High-Speed RAM Disk Recording**
```bash
# Start recording with RAM disk (requires sudo)
sudo python3 install/data_recorder/lib/data_recorder/ramdisk_control.py start

# Stop recording and backup to SD card
sudo python3 install/data_recorder/lib/data_recorder/ramdisk_control.py stop

# Check status
python3 install/data_recorder/lib/data_recorder/ramdisk_control.py status
```

## 📊 **Performance Comparison**

| Method | Write Speed | Use Case | Pros | Cons |
|---|---|---|---|---|
| **SD Card** | ~20 MB/s | Standard recording | Simple, persistent | Slower, wear |
| **RAM Disk** | ~500 MB/s | High-speed recording | Very fast, no wear | Requires sudo, temporary |

## 🎯 **When to Use Each Method**

### **Use SD Card Recording When:**
- Simple data collection
- Long recording sessions
- No sudo access available
- Standard performance is sufficient

### **Use RAM Disk Recording When:**
- High-speed data collection needed
- Short recording sessions
- Sudo access available
- Maximum performance required

## 🔧 **Configuration Options**

### **Output Location**
```bash
# Custom output directory
ros2 launch data_recorder data_recorder_with_camera.launch.py output_dir:=/path/to/your/data

# RAM disk with custom backup location
sudo python3 install/data_recorder/lib/data_recorder/ramdisk_recorder.py \
  --backup-path /path/to/backup --start
```

### **Multi-Robot Setup**
```bash
# Robot 1
ROS_NAMESPACE=robot1 ros2 launch data_recorder data_recorder_with_camera.launch.py

# Robot 2
ROS_NAMESPACE=robot2 ros2 launch data_recorder data_recorder_with_camera.launch.py
```

### **Camera Configuration**
```bash
# Use libcamera (Pi HQ Camera)
ros2 launch data_recorder data_recorder_with_camera.launch.py camera_type:=libcamera

# Use v4l2 (USB cameras)
ros2 launch data_recorder data_recorder_with_camera.launch.py camera_type:=v4l2
```

## 📁 **Data Structure**

Both methods create the same data structure:

```
output_directory/
└── session_YYYYMMDD_HHMMSS/
    ├── images/
    │   ├── 00000000.jpg
    │   ├── 00000001.jpg
    │   └── ...
    └── metadata/
        └── data_log.csv
```

## 🎮 **Complete Workflow Examples**

### **1. Basic Data Collection**
```bash
# Start recording
ros2 launch data_recorder data_recorder_with_camera.launch.py

# Do teleoperation
# ... drive your robot ...

# Stop recording
python3 install/data_recorder/lib/data_recorder/record_control.py stop
```

### **2. High-Speed Data Collection**
```bash
# Start RAM disk recording
sudo python3 install/data_recorder/lib/data_recorder/ramdisk_control.py start

# Do teleoperation
# ... drive your robot ...

# Stop and backup
sudo python3 install/data_recorder/lib/data_recorder/ramdisk_control.py stop
```

### **3. Multi-Robot Data Collection**
```bash
# Terminal 1 - Robot 1
ROS_NAMESPACE=robot1 ros2 launch data_recorder data_recorder_with_camera.launch.py

# Terminal 2 - Robot 2
ROS_NAMESPACE=robot2 ros2 launch data_recorder data_recorder_with_camera.launch.py

# Control each robot separately
ROS_NAMESPACE=robot1 python3 install/data_recorder/lib/data_recorder/record_control.py start
ROS_NAMESPACE=robot2 python3 install/data_recorder/lib/data_recorder/record_control.py start
```

### **4. YOLO Training Data Preparation**
```bash
# Record data
ros2 launch data_recorder data_recorder_with_camera.launch.py

# Prepare for Label Studio
python3 install/data_recorder/lib/data_recorder/prepare_for_labelstudio.py \
  /home/rcr/teleop_data/session_*/images

# After annotation, combine with motor data
python3 install/data_recorder/lib/data_recorder/combine_yolo_with_motor_data.py \
  /path/to/labelstudio/export \
  /home/rcr/teleop_data/session_*/metadata/data_log.csv
```

## 🚨 **Important Notes**

### **RAM Disk Recording**
- **Requires sudo privileges**
- **Data is lost on reboot** (unless backed up)
- **Uses system RAM** (may affect performance)
- **Always use `--stop` to backup data**

### **SD Card Recording**
- **No special privileges needed**
- **Data persists on reboot**
- **Slower write speeds**
- **May wear out SD card over time**

### **General**
- **Check available space** before recording
- **Monitor system resources** during recording
- **Use appropriate method** for your use case

## 🔍 **Troubleshooting**

### **Common Issues**

#### **"Permission denied" (RAM disk)**
```bash
# Solution: Use sudo
sudo python3 install/data_recorder/lib/data_recorder/ramdisk_control.py start
```

#### **"No space left on device"**
```bash
# Check available space
df -h

# Free up space or use different location
ros2 launch data_recorder data_recorder_with_camera.launch.py output_dir:=/path/with/space
```

#### **"Data recorder not starting"**
```bash
# Check ROS2 environment
source /opt/ros/humble/setup.bash
source install/setup.bash

# Check if camera is available
ros2 topic list | grep camera
```

#### **"Camera not found"**
```bash
# Check camera devices
ls /dev/video*
ls /dev/media*

# Test camera
python3 install/data_recorder/lib/data_recorder/test_libcamera.py
```

## 📚 **Additional Resources**

- **RAMDISK_README.md** - Detailed RAM disk documentation
- **README.md** - Complete package documentation
- **test_ramdisk.py** - Test RAM disk functionality
- **test_libcamera.py** - Test camera functionality
- **test_namespace.py** - Test namespace functionality

## 🎯 **Next Steps**

1. **Choose your recording method** (SD card or RAM disk)
2. **Test the setup** with the test scripts
3. **Start recording** your training data
4. **Process data** for neural network training
5. **Annotate data** with Label Studio (if needed)
6. **Train your models** with the collected data

The data recorder is now ready for high-quality data collection for your neural network training!

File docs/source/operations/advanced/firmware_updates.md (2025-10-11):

# Flashing the Teensy Microcontroller

This guide covers how to flash firmware to the Teensy 4.0 microcontroller on the RCR Common Robotics Platform.

## Overview

Firmware runs on the Teensy 4.0 microcontroller. It sets up ROS2 nodes that run on the Teensy, but communicate with the larger ROS2 environment via a bridge node called the microros agent that runs on the RPi5.

## Flashing Procedure

### 1. Navigate to the firmware directory and replace the build folder
   ```bash
   cd ~/repos/common_platform/firmware/closed_loop/
   rm -rf build
   mkdir build
   cd build
   ```

### 2. Compile the firmware for Teensy 4.0
   ```bash
   arduino-cli compile --fqbn teensy:avr:teensy40 --build-property build.usbtype=USB_DUAL_SERIAL --build-path . ../closed_loop.ino
   ```

### 3. Find the Teensy device (first power the Teensy - i.e. put in the lower-half batteries)
   ```bash
   SERIAL_TEENSY_DEVICE=`find /dev/serial/by-id/ -name "usb-Teensyduino*if00"|head -1`
   echo "-> Performing soft reset (baud = 134 hack). $SERIAL_TEENSY_DEVICE"
   ```

### 4. Reset Teensy into programming mode
   ```bash
   stty -F $SERIAL_TEENSY_DEVICE 9600
   stty -F $SERIAL_TEENSY_DEVICE 134
   ```

### 5. Verify the Teensy is ready
   ```bash
   lsusb | grep Teensy; echo "-> Should be ready to program if lsusb reports a Bootloader device…"
   ```

### 6. Upload the new firmware
   ```bash
   sudo teensy_loader_cli -v --mcu=TEENSY40 closed_loop.ino.hex
   ```

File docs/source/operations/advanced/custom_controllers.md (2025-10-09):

# Custom Controllers

This guide covers advanced controller configuration and customization for the RCR Common Robotics Platform.

## Overview

Custom controllers allow you to implement advanced control algorithms, optimize performance, and add new functionality to your robot.

## Prerequisites

- Understanding of control theory
- Familiarity with ROS2 control
- Knowledge of robot kinematics
- Experience with C++ or Python

## Controller Types

### 1. Motion Controllers

**Differential Drive Controller:**
- Controls left and right wheels
- Implements velocity commands
- Handles odometry feedback

**Omni-Drive Controller:**
- Controls multiple wheels
- Implements holonomic motion
- Advanced kinematics

### 2. Sensor Controllers

**LiDAR Controller:**
- Manages LiDAR data
- Implements filtering
- Handles calibration

**Camera Controller:**
- Manages camera data
- Implements image processing
- Handles calibration

## Controller Development

### 1. Basic Controller Structure

**C++ Controller:**
```cpp
#include <controller_interface/controller_interface.hpp>
#include <hardware_interface/types/hardware_interface_type_values.hpp>

class CustomController : public controller_interface::ControllerInterface
{
public:
  CustomController();
  ~CustomController();

  controller_interface::return_type init(
    const std::string & controller_name) override;

  controller_interface::return_type update() override;

private:
  // Controller implementation
};
```

**Python Controller:**
```python
import rclpy
from controller_interface import ControllerInterface

class CustomController(ControllerInterface):
    def __init__(self):
        super().__init__()

    def init(self, controller_name):
        # Initialize controller
        pass

    def update(self):
        # Update controller
        pass
```

### 2. Controller Configuration

**Controller Parameters:**
```yaml
custom_controller:
  ros__parameters:
    # Controller parameters
    update_rate: 100.0
    control_mode: velocity

    # PID parameters
    p_gain: 1.0
    i_gain: 0.0
    d_gain: 0.0

    # Safety parameters
    max_velocity: 1.0
    max_acceleration: 2.0
```

### 3. Controller Integration

**Hardware Interface:**
```yaml
hardware:
  ros__parameters:
    joints:
      - left_wheel
      - right_wheel

    interfaces:
      - position
      - velocity
      - effort
```

**Controller Manager:**
```yaml
controller_manager:
  ros__parameters:
    update_rate: 100

    controllers:
      custom_controller:
        type: custom_controller/CustomController
```

## Advanced Control Algorithms

### 1. PID Control

**PID Implementation:**
```cpp
class PIDController
{
public:
  PIDController(double p, double i, double d);
  double update(double error, double dt);

private:
  double p_gain_, i_gain_, d_gain_;
  double integral_, previous_error_;
};
```

**PID Tuning:**
- Start with P gain only
- Add I gain for steady-state error
- Add D gain for stability
- Tune for performance

### 2. Model Predictive Control

**MPC Implementation:**
- Predict future behavior
- Optimize control inputs
- Handle constraints
- Real-time optimization

### 3. Adaptive Control

**Adaptive Algorithms:**
- Self-tuning controllers
- Parameter estimation
- Robust control
- Learning control

## Performance Optimization

### 1. Real-time Performance

**Timing Requirements:**
- Control loop frequency
- Latency constraints
- Jitter minimization
- Priority scheduling

**Optimization Techniques:**
- Efficient algorithms
- Memory management
- CPU optimization
- Real-time scheduling

### 2. Control Performance

**Performance Metrics:**
- Tracking accuracy
- Response time
- Stability margins
- Robustness

**Optimization Methods:**
- Parameter tuning
- Algorithm selection
- Hardware optimization
- System integration

## Testing and Validation

### 1. Simulation Testing

**Gazebo Simulation:**
```bash
# Launch simulation
ros2 launch common_platform launch_sim.launch.py

# Test controller
ros2 run custom_controller test_controller
```

**Controller Testing:**
- Unit tests
- Integration tests
- Performance tests
- Safety tests

### 2. Hardware Testing

**Safe Testing:**
- Start with low gains
- Test in safe environment
- Monitor system behavior
- Have emergency stop ready

**Validation Procedures:**
- Step response tests
- Frequency response tests
- Stability tests
- Performance tests

## Troubleshooting

### Common Issues

**Controller Not Starting:**
- Check configuration
- Verify hardware interface
- Check for errors
- Review logs

**Poor Performance:**
- Tune parameters
- Check sensor data
- Verify timing
- Review algorithms

**Instability:**
- Reduce gains
- Check for delays
- Verify system model
- Review stability

### Diagnostic Tools

**Controller Monitoring:**
```bash
# Monitor controller status
ros2 control list_controllers

# Check controller parameters
ros2 param list /controller_manager

# Monitor performance
ros2 run rqt_plot rqt_plot
```

## Best Practices

### Development

**Code Quality:**
- Follow coding standards
- Use version control
- Document code
- Test thoroughly

**Safety:**
- Implement safety checks
- Use appropriate limits
- Handle failures gracefully
- Test extensively

### Deployment

**Configuration Management:**
- Version control configurations
- Document changes
- Test in simulation first
- Deploy gradually

**Monitoring:**
- Monitor performance
- Check for errors
- Log important events
- Maintain backups

---

*For firmware updates, see [Firmware Updates](firmware_updates.md)*
*For troubleshooting, see [Troubleshooting](../troubleshooting/index.md)*

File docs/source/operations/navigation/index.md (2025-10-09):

# Navigation Operations

This section covers navigation-related operations for the RCR Common Robotics Platform.

## Prerequisites

- **Discovery Server Running**: Ensure a ROS discovery server is running (see [Discovery Server Setup](../discovery_server.md))
- Robot hardware properly assembled and calibrated
- LiDAR sensor functioning correctly
- Odometry system working (wheel encoders and/or IMU)
- Sufficient battery charge

## Navigation Procedures

### Mapping and Localization
- [Mapping](mapping.md) - Creating and updating maps
- [Localization](localization.md) - Robot positioning and localization
- [Path Planning](path_planning.md) - Navigation and path planning

## Navigation Overview

The navigation system consists of several key components:

1. **Mapping** - Creating maps of the environment
2. **Localization** - Determining robot position
3. **Path Planning** - Planning routes to destinations
4. **Obstacle Avoidance** - Avoiding obstacles during navigation

## Quick Start

### Basic Navigation
```bash
# Launch navigation system
ros2 launch common_platform navigation_launch.py

# Set navigation goal
ros2 run nav2_util navigation_goal --x 2.0 --y 1.0 --yaw 0.0
```

### Mapping
```bash
# Launch SLAM
ros2 launch common_platform cartographer_2d.launch.py

# Save map
ros2 run nav2_map_server map_saver_cli -f my_map
```

## Navigation Components

### Sensors
- LiDAR for obstacle detection
- IMU for orientation
- Odometry for position tracking

### Software
- ROS2 Navigation2 stack
- Cartographer for SLAM
- AMCL for localization

## Troubleshooting

Common navigation issues:
- Localization failures
- Path planning errors
- Obstacle detection problems

See [Troubleshooting](../troubleshooting/index.md) for solutions.

---

*For setup procedures, see [Setup](../setup/index.md)*
*For troubleshooting, see [Troubleshooting](../troubleshooting/index.md)*

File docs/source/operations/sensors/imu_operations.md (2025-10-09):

# IMU Operations

This guide covers IMU (Inertial Measurement Unit) operations, setup, and troubleshooting for the RCR Common Robotics Platform.

## Overview

The robot uses an IMU for orientation sensing, motion detection, and navigation. The IMU provides acceleration, angular velocity, and orientation data.

## IMU Specifications

- **Model**: MPU9250
- **Accelerometer**: ±16g range
- **Gyroscope**: ±2000°/s range
- **Magnetometer**: ±4800μT range
- **Interface**: I2C
- **Update Rate**: 100 Hz

## IMU Setup

### 1. Hardware Connection

1. **Physical Mounting**
   - Mount IMU in stable location
   - Minimize vibration
   - Ensure proper orientation

2. **Power Connection**
   - Connect to robot power system
   - Verify voltage requirements (3.3V)
   - Check for proper grounding

3. **Data Connection**
   - Connect to I2C bus
   - Verify pull-up resistors
   - Test communication

### 2. Software Configuration

**Launch IMU:**
```bash
# Launch IMU node
ros2 launch common_platform imu.launch.py
```

**Verify Data:**
```bash
# Check IMU data
ros2 topic echo /${ROS_NAME}/imu/data

# Monitor data rate
ros2 topic hz /${ROS_NAME}/imu/data
```

## IMU Calibration

### 1. Static Calibration

**Calibration Process:**
1. Place robot on level surface
2. Ensure no movement
3. Run calibration procedure
4. Save calibration parameters

**Calibration Command:**
```bash
# Run IMU calibration
ros2 run imu_calibration calibrate_imu
```

### 2. Dynamic Calibration

**Motion Calibration:**
- Perform controlled movements
- Calibrate gyroscope bias
- Verify acceleration readings

**Orientation Calibration:**
- Align with known orientation
- Calibrate magnetometer
- Verify heading accuracy

## IMU Data Analysis

### 1. Data Structure

**IMU Message:**
```yaml
std_msgs/Header header
geometry_msgs/Quaternion orientation
float64[9] orientation_covariance
geometry_msgs/Vector3 angular_velocity
float64[9] angular_velocity_covariance
geometry_msgs/Vector3 linear_acceleration
float64[9] linear_acceleration_covariance
```

### 2. Data Quality

**Check Data Quality:**
```bash
# Monitor IMU data
ros2 topic echo /imu/data

# Check for:
# - Stable orientation
# - Reasonable acceleration values
# - Consistent angular velocity
```

## IMU Applications

### 1. Orientation Sensing

**Quaternion Data:**
- Use for robot orientation
- Implement orientation control
- Monitor attitude changes

**Euler Angles:**
- Convert for human readability
- Use for control algorithms
- Monitor pitch, roll, yaw

### 2. Motion Detection

**Acceleration Data:**
- Detect motion changes
- Implement motion control
- Monitor for impacts

**Angular Velocity:**
- Detect rotation
- Implement rotation control
- Monitor for spinning

### 3. Navigation

**Sensor Fusion:**
- Combine with other sensors
- Improve localization
- Enhance navigation accuracy

**Dead Reckoning:**
- Use for short-term navigation
- Complement other sensors
- Handle sensor failures

## Troubleshooting

### Common Issues

**No IMU Data:**
- Check I2C connection
- Verify power supply
- Check device address
- Test with I2C tools

**Poor Data Quality:**
- Check mounting stability
- Verify calibration
- Test in different environments
- Check for interference

**Drift Issues:**
- Recalibrate IMU
- Check for temperature effects
- Verify mounting
- Test with known orientations

### Diagnostic Commands

```bash
# Check I2C devices
i2cdetect -y 1

# Test I2C communication
i2cget -y 1 0x68 0x75

# Monitor data quality
ros2 topic echo /imu/data
ros2 topic hz /imu/data
```

### Error Codes

**Common Error Messages:**
- "Failed to open I2C device" - Check I2C connection
- "No data received" - Check power and connections
- "Invalid data" - Check for interference or damage

## Maintenance

### Regular Maintenance

**Daily:**
- Visual inspection
- Check for vibration
- Verify data quality

**Weekly:**
- Check mounting stability
- Test calibration
- Monitor performance

**Monthly:**
- Full calibration check
- Performance testing
- Connection inspection

### Cleaning Procedures

**IMU Unit:**
1. Power off robot
2. Clean mounting surface
3. Check for loose connections
4. Verify stability

**Mounting Area:**
- Clean mounting surface
- Check for loose connections
- Verify stability

## Performance Optimization

### Data Processing

**Filtering:**
- Remove noise from data
- Implement low-pass filters
- Smooth data for better performance

**Sensor Fusion:**
- Combine with other sensors
- Use Kalman filters
- Improve accuracy

### Parameter Tuning

**IMU Parameters:**
```yaml
# In launch file
update_rate: 100
linear_acceleration_stddev: 0.01
angular_velocity_stddev: 0.01
```

**Filter Parameters:**
- Adjust filter gains
- Balance performance vs. accuracy
- Consider computational load

## Safety Considerations

### Operating Safety

- Handle with care during maintenance
- Follow manufacturer guidelines
- Consider temperature effects
- Monitor for failures

### Data Safety

- Verify data accuracy
- Handle sensor failures gracefully
- Implement appropriate logging
- Consider data validation

---

*For LiDAR operations, see [LiDAR Operations](lidar_operations.md)*
*For camera operations, see [Camera Operations](../../camera/camera_operations.md)*
*For troubleshooting, see [Troubleshooting](../troubleshooting/index.md)*

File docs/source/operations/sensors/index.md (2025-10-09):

# Sensor Operations

This section covers sensor operations and maintenance for the RCR Common Robotics Platform.

## Sensor Types

### LiDAR Operations
- [LiDAR Operations](lidar_operations.md) - LiDAR setup and troubleshooting

### Camera Operations
- [Camera Operations](../../camera/camera_operations.md) - Camera configuration and usage

### IMU Operations
- [IMU Operations](imu_operations.md) - IMU calibration and monitoring

## Sensor Overview

The robot is equipped with several key sensors:

1. **LiDAR** - For obstacle detection and mapping
2. **Camera** - For visual perception and navigation
3. **IMU** - For orientation and motion sensing
4. **Encoders** - For wheel odometry

## Quick Reference

### Check Sensor Status
```bash
# List all sensor topics
ros2 topic list | grep -E "(scan|camera|imu|odom)"

# Check sensor data rates
ros2 topic hz /${ROS_NAME}/scan
ros2 topic hz /${ROS_NAME}/camera/image_raw
ros2 topic hz /${ROS_NAME}/imu/data
```

### Common Commands
```bash
# Launch sensors
ros2 launch common_platform camera.launch.py
ros2 launch common_platform rplidar.launch.py

# Monitor sensor data
ros2 topic echo /${ROS_NAME}/scan
ros2 topic echo /${ROS_NAME}/camera/image_raw
ros2 topic echo /${ROS_NAME}/imu/data
```

## Troubleshooting

Common sensor issues:
- No data from sensors
- Poor data quality
- Calibration problems
- Connection issues

See [Troubleshooting](../troubleshooting/index.md) for solutions.

---

*For setup procedures, see [Setup](../setup/index.md)*
*For troubleshooting, see [Troubleshooting](../troubleshooting/index.md)*

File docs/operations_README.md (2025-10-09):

# Robot Operations Documentation

This directory contains the robot operations documentation for the RCR Common Robotics Platform. The documentation is integrated into the main Sphinx documentation system and can be built alongside the rest of the project documentation.

## File Structure

```
docs/source/operations/
├── index.md                      # Main operations manual index
├── setup/                        # Initial setup and configuration
│   ├── index.md
│   ├── hardware_setup.md
│   ├── software_setup.md
│   └── calibration.md
├── daily_operations/             # Routine operations
│   ├── index.md
│   ├── startup_procedure.md
│   ├── shutdown_procedure.md
│   └── maintenance.md
├── navigation/                   # Navigation-related operations
│   ├── index.md
│   ├── mapping.md
│   ├── localization.md
│   └── path_planning.md
├── sensors/                      # Sensor operations
│   ├── index.md
│   ├── lidar_operations.md
│   ├── camera_operations.md
│   └── imu_operations.md
├── troubleshooting/              # Problem-solving guides
│   ├── index.md
│   ├── common_issues.md
│   ├── error_codes.md
│   └── recovery_procedures.md
└── advanced/                     # Advanced operations
    ├── index.md
    ├── custom_controllers.md
    └── firmware_updates.md
```

## Building the Documentation

### Prerequisites

1. Install Python virtual environment support:
   ```bash
   sudo apt install python3.12-venv
   ```

2. Create and activate a virtual environment:
   ```bash
   cd docs
   python3 -m venv venv
   source venv/bin/activate
   ```

3. Install documentation dependencies:
   ```bash
   pip install -r requirements.txt
   ```

### Building

1. Build the HTML documentation:
   ```bash
   make html
   ```

2. View the documentation:
   ```bash
   # Open in browser
   firefox build/html/index.html
   ```

### Alternative Build Methods

If you prefer not to use a virtual environment:

1. Install system packages:
   ```bash
   sudo apt install python3-sphinx python3-sphinx-rtd-theme
   pip install myst-parser --break-system-packages
   ```

2. Build directly:
   ```bash
   sphinx-build -b html source build
   ```

## Adding New Operations

### Creating New Operation Files

1. **Choose the appropriate category** (setup, daily_operations, navigation, etc.)
2. **Create the markdown file** with a descriptive name
3. **Update the category index.md** to include the new file
4. **Follow the established format** (see existing files for examples)

### File Naming Conventions

- Use lowercase with underscores: `hardware_setup.md`
- Be descriptive: `lidar_operations.md` not `lidar.md`
- Use consistent terminology across files

### Content Guidelines

1. **Structure**: Use clear headings and sections
2. **Safety**: Always include safety warnings where appropriate
3. **Prerequisites**: List what's needed before starting
4. **Step-by-step**: Provide clear, numbered procedures
5. **Troubleshooting**: Include common issues and solutions
6. **Cross-references**: Link to related procedures

### Example File Structure

```markdown
# Operation Title

Brief description of what this operation does.

## Prerequisites

- List of requirements
- Tools needed
- Knowledge prerequisites

## Procedure

### Step 1: Preparation
Detailed steps...

### Step 2: Execution
Detailed steps...

## Verification

How to verify the operation was successful.

## Troubleshooting

Common issues and solutions.

## Safety Notes

⚠️ Important safety information.

## Related Operations

- [Link to related procedure](link.md)
```

## Integration with Main Documentation

The operations documentation is automatically included in the main documentation build through the `index.rst` file, which includes:

```rst
.. toctree::
   :maxdepth: 2
   :caption: Contents:

   intro
   hardware
   software
   testing
   operations/index
```

This means the operations manual will appear as a top-level section in the generated documentation.

## Maintenance

### Regular Updates

- Review procedures quarterly
- Update when hardware/software changes
- Incorporate user feedback
- Keep safety information current

### Version Control

- Commit changes with descriptive messages
- Tag major updates
- Maintain change log
- Document breaking changes

## Contributing

To contribute to the operations documentation:

1. **Fork the repository**
2. **Create a feature branch**
3. **Make your changes**
4. **Test the documentation build**
5. **Submit a pull request**

### Review Process

- Technical accuracy review
- Safety review
- Usability testing
- Documentation standards compliance

---

*This documentation structure provides a comprehensive, maintainable system for robot operations that integrates seamlessly with your existing Sphinx documentation system.*

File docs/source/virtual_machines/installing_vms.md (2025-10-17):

# Virtual Machine Setup

If you're developing for the common platform robot on Windows or macOS, you'll need to set up a virtual machine (VM) running Ubuntu 24.04. This is necessary because ROS2 runs natively on Ubuntu, and while you can SSH into the robot's Raspberry Pi for many tasks, having a local development environment with RViz and other ROS2 tools is essential for SLAM visualization and real time camera feeds.

There are two recommended approaches:
- **Windows**: Using Windows Subsystem for Linux (WSL)
- **macOS**: Using Parallels Desktop

Both methods will allow you to run Ubuntu 24.04 with full ROS2 Kilted Desktop installation, including RViz for 3D visualization and all the tools you need for robot development.

## Windows: WSL Setup

Windows Subsystem for Linux (WSL) is Microsoft's solution for running a full Linux environment directly on Windows. It provides excellent performance and seamless integration with Windows, making it ideal for ROS2 development.

### Windows Firewall Configuration

**Important:** Windows Defender Firewall can block ROS2 communication between WSL and Windows. If you experience connectivity issues with ROS2 nodes or RViz, you may need to temporarily disable the firewall.

#### Check Firewall Status

Open **PowerShell as Administrator** and run:

```powershell
Get-NetFirewallProfile | Format-Table Name, Enabled
```

This will show which firewall profiles are enabled.

#### Temporarily Disable Firewall (if needed)

If any profiles show `Enabled = True` and you're experiencing ROS2 connectivity issues, disable them:

```powershell
Set-NetFirewallProfile -Profile Domain,Public,Private -Enabled False
```

**⚠️ Security Warning:** Remember to re-enable the firewall after testing. We are working on creating specific firewall rules that allow ROS2 traffic without disabling the entire firewall.

### Installing WSL with Ubuntu 24.04

**Open PowerShell as Administrator** and install WSL with Ubuntu 24.04:
   ```powershell
   wsl --install -d Ubuntu-24.04
   ```

**Restart your computer** when prompted.

**Launch Ubuntu** from the Start menu and create your user account when prompted.

**Update your system packages**:
   ```bash
   sudo apt update
   ```

## macOS: Parallels Setup

Parallels Desktop is a powerful virtualization solution for macOS that provides excellent performance for running Ubuntu alongside macOS.

### Installing Parallels and Ubuntu

**Download and install Parallels Desktop** from [parallels.com](https://www.parallels.com)

**Create a new virtual machine**:
   - Open Parallels Desktop
   - Click "+" to create a new VM
   - Select "Install Windows or another OS from a DVD or image file"
   - Download Ubuntu 24.04 LTS Desktop ISO from [ubuntu.com](https://ubuntu.com/download/desktop)
   - Follow the installation wizard to complete setup

**Configure VM resources** (recommended settings):
   - Memory: At least 4GB RAM (8GB recommended)
   - Processors: 2-4 CPU cores
   - Disk space: 40GB or more
   - Graphics: Enable 3D acceleration for better RViz performance

**Install Parallels Tools** for better integration:
   - In Parallels menu, select "Install Parallels Tools"
   - Follow the on-screen instructions
   - Restart the VM when complete

### Optimizing Performance

For the best ROS2 and RViz experience on Parallels:
- Enable "Use Mac GPU for Windows" in VM configuration
- Set graphics to "Better performance" mode
- Allocate sufficient RAM for visualization tasks

## Alternative Options

While WSL and Parallels are our recommended solutions, other virtualization options include:
- **VirtualBox**: Free and open-source, works on both Windows and macOS
- **VMware**: Commercial virtualization software with good performance
- **UTM**: Free virtualization for macOS (especially for Apple Silicon Macs)

**Note:** These alternatives are not officially documented or tested with this platform, but may work for your needs.

## Installing ROS2 Kilted

Once you have Ubuntu 24.04 running (via WSL, Parallels, or another method), you'll need to install ROS2 Kilted Desktop, which includes RViz and all the visualization tools you'll need.

### ROS2 Kilted Desktop Installation

Follow the official ROS2 installation instructions for Ubuntu:

**🔗 Installation Guide**: [https://docs.ros.org/en/kilted/Installation/Ubuntu-Install-Debs.html](https://docs.ros.org/en/kilted/Installation/Ubuntu-Install-Debs.html)

### Verifying Your Installation

Check for ROS2
   ```bash
   which ros2
   ```
Should return `/opt/ros/kilted/bin/ros2`

Test RViz
   ```bash
   rviz2
   ```
This should open up RViz tool GUI, if it does you can close this for now and continue setting up the config.

### After Installing ROS

On the VM you will need to set up a few configuration files and environment variables.

#### Edit the .profile
```bash
sudo nano ~/.profile
```

Add the following to the bottom of the .profile, then save and exit the file
```

source /opt/ros/kilted/setup.bash
export ROS_DOMAIN_ID=0
export RMW_IMPLEMENTATION=rmw_fastrtps_cpp
export ROS_SUPER_CLIENT=true
export FASTDDS_DEFAULT_PROFILES_FILE=/home/${USER}/ros2_ws/super_client_configuration_file_rcr.xml
ros2 daemon stop; ros2 daemon start
```
source .profile so the changes take effect in your current session
```bash
source ~/.profile
```

#### Set up the Discovery Server

Now that you have ROS2 on your VM, you will need to point it to the proper discovery server so it can communicate with your robot via ROS. To do this, first create the directory if it doesn't already exist:

```bash
mkdir ~/ros2_ws
```
Then edit or create the discovery server config file referenced in the environment variable above.

```bash
nano ~/ros2_ws/super_client_configuration_file_rcr.xml
```

The config file should look something like this, if not paste the code below into your config file.

```xml
<profiles xmlns="http://www.eprosima.com/XMLSchemas/fastRTPS_Profiles">
  <participant profile_name="super_client_profile" is_default_profile="true">
    <rtps>
      <builtin>
        <discovery_config>
          <discoveryProtocol>SUPER_CLIENT</discoveryProtocol>
          <discoveryServersList>
            <locator>
              <udpv4>
                <address>127.0.0.1</address>
                <port>11811</port>
              </udpv4>
            </locator>
          </discoveryServersList>
        </discovery_config>
      </builtin>
    </rtps>
  </participant>
</profiles>
```
Edit line 11 to set the proper discovery server IP address. If you are running the discovery server on your own Pi, then it should work as is. If you are at the RCR lab, change it to Joe's IP which is `192.168.1.125`. If neither work, figure out what IP address you can ping the discovery server at and use that. See more **[troubleshooting tips here](#troubleshooting-vm-connectivity-to-discovery-server)**.

Save the file above, then stop and start the ros2 daemon

```bash
ros2 daemon stop
ros2 daemon start
```

Testing - check for ROS topics
```bash
ros2 topic list
```

You should now see the full list of ROS topics publishing from the discovery server.

### Troubleshooting VM connectivity to discovery server

If you're having trouble connecting your VM to the discovery server, follow these troubleshooting steps:

#### Network Configuration

Your VM must be configured to use the same network and IP address as your host computer. This requires specific network settings:

**For WSL (Windows):** Configure **mirrored networking** so your VM shares the same IP address as Windows
- 📖 [WSL Networking Documentation](https://learn.microsoft.com/en-us/windows/wsl/networking)

**For Parallels (macOS):** Set up **bridged networking mode**
- 📖 [Parallels Network Settings Documentation](https://docs.parallels.com/pdfm-ug-20/parallels-desktop-for-mac-20-users-guide/parallels-desktop-preferences-and-virtual-machine-settings/virtual-machine-settings/ha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)

#### Connectivity Tests

Test internet connectivity:
```bash
ping google.com
```

Test connection to your robot (replace `n` with your robot's IP):
```bash
ping 192.168.1.n
```

Test connection to the discovery server:
```bash
ping 192.168.1.125 # for Joe's computer
```

#### Other Common Issues:
- check firewalls - see [Firewall Configuration](#windows-firewall-configuration)
- check your IP address on both your laptop and your VM - they should match. If not, see

## Troubleshooting Graphics Issues

If you encounter graphics or rendering issues when running RViz or other GUI applications in your VM, you may need to enable software rendering.

### Enable Software Rendering

Set this environment variable to force software rendering:

```bash
export LIBGL_ALWAYS_SOFTWARE=1
```

**When to use this:**
- RViz crashes on startup with OpenGL errors
- You see graphics driver warnings
- 3D visualization is not working properly
- Running in a VM without proper GPU acceleration

**Note:** Software rendering will be slower than hardware acceleration, but it ensures compatibility across different VM configurations.

## Next Steps

Now that you have your development environment set up, you can:

- [Visualize sensor data with RViz](rviz_sensor_visualization.md)
- [Set up real-time camera feed](realtime_camera_video.md)

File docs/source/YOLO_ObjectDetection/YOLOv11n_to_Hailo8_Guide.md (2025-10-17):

# YOLOv11n to Hailo-8 HEF Compilation Guide

This guide describes how to convert a **fine-tuned YOLOv11n model** (from Ultralytics) into a **Hailo Executable File (.hef)** for use on the Raspberry Pi AI Kit with the Hailo-8 accelerator.
**NOTE: These steps can only be completed on an Ubuntu computer with x86_64 architecture. It is best with a CUDA GPU.**
[Complete the steps in this document first](./YOLOv11n_Finetuning_Workflow.md)

---

## 0. Environment Setup

Before compiling models, you need to set up the Hailo development environment.

### Prerequisites

- **Ubuntu 20.04 or 22.04** (x86_64)
- **16GB+ RAM** (32GB recommended)
- **NVIDIA GPU with CUDA support** (optional but strongly recommended for faster compilation)
- **50GB+ free disk space**

Native installation provides better GPU access and is generally more reliable.

1. **Download Hailo Wheel Files**

   Visit the [Hailo Developer Zone](https://hailo.ai/developer-zone/) and download the required wheel files directly:

   - `hailo_dataflow_compiler-3.33.0-py3-none-linux_x86_64.whl`
   - `hailort-4.23.0-cp310-cp310-linux_x86_64.whl`
   - `hailo_model_zoo-2.17.0-py3-none-any.whl`

2. **Install Prerequisites**

   Install all required packages:

   ```bash
   sudo apt update
   sudo apt install -y python3.10 python3.10-venv python3.10-dev python3-pip \
     git wget build-essential python3-tk graphviz libgraphviz-dev
   ```

3. **Install CUDNN (Recommended for GPU Acceleration)**

   **Important:** CUDNN version must match your CUDA version. Check first:

   ```bash
   # Check your CUDA version
   nvcc --version
   nvidia-smi  # Look at "CUDA Version" in the output
   ```

   Download and install the matching CUDNN:

   ```bash
   # Download CUDNN from NVIDIA (requires free account)
   # Visit: https://developer.nvidia.com/cudnn-downloads
   # Select: CUDNN for CUDA 12.x, Linux x86_64, Ubuntu 22.04

   # Example installation (adjust version as needed):
   wget https://developer.download.nvidia.com/compute/cudnn/9.14.0/local_installers/cudnn-local-repo-ubuntu2204-9.14.0_1.0-1_amd64.deb
   sudo dpkg -i cudnn-local-repo-ubuntu2204-9.14.0_1.0-1_amd64.deb
   sudo cp /var/cudnn-local-repo-ubuntu2204-9.14.0/cudnn-*-keyring.gpg /usr/share/keyrings/
   sudo apt update
   
   # CRITICAL: Install CUDNN for YOUR CUDA version (e.g., cuda-12 for CUDA 12.x)
   # Check available packages:
   apt-cache search cudnn | grep cuda-
   
   # For CUDA 12.x:
   sudo apt install -y cudnn9-cuda-12 libcudnn9-cuda-12 libcudnn9-dev-cuda-12
   
   # For CUDA 11.x:
   # sudo apt install -y cudnn9-cuda-11 libcudnn9-cuda-11 libcudnn9-dev-cuda-11
 
   # Verify installation
   sudo ldconfig
   ldconfig -p | grep cudnn
   # Should show multiple libcudnn*.so files
   ```

   **Troubleshooting CUDNN Installation:**
   
   ```bash
   # Check if CUDNN was actually installed
   dpkg -l | grep cudnn
   
   # Check for version mismatch (common issue!)
   # If you see "cuda-13" but have CUDA 12.x, that's wrong!
   nvcc --version  # Your actual CUDA version
   dpkg -l | grep cudnn | grep cuda-  # What CUDNN thinks it's for
   
   # If there's a mismatch, remove wrong version and install correct one:
   # For CUDA 12.x with wrong CUDNN 13:
   sudo apt remove -y cudnn9-cuda-13* libcudnn9-cuda-13* libcudnn9-dev-cuda-13*
   sudo apt install -y cudnn9-cuda-12 libcudnn9-cuda-12 libcudnn9-dev-cuda-12
   
   # Refresh library cache
   sudo ldconfig
   
   # Verify again
   ldconfig -p | grep cudnn
   ```

   **If you still can't install CUDNN, you can use CPU-only mode:**
   
   ```bash
   # Force TensorFlow to use CPU instead of GPU
   export CUDA_VISIBLE_DEVICES=""
   
   # Add to your environment permanently
   echo 'export CUDA_VISIBLE_DEVICES=""' >> ~/hailo_env/bin/activate
   ```

   > **Note:** Without CUDNN, Hailo tools will error when trying to use GPU. Use `CUDA_VISIBLE_DEVICES=""` to force CPU mode. Compilation will be slower but still work.

4. **Create Clean Python Environment**

   **Recommended approach:** Create a fresh virtual environment and install only the wheel files:

   ```bash
   # Create a new virtual environment
   python3 -m venv hailo_venv
   cd hailo_venv/
   source bin/activate
   
   # Upgrade pip
   pip install --upgrade pip
   
   # Install Hailo wheel files (adjust paths as needed)
   pip install ../hailo_dataflow_compiler-3.33.0-py3-none-linux_x86_64.whl
   pip install ../hailort-4.23.0-cp310-cp310-linux_x86_64.whl
   pip install ../hailo_model_zoo-2.17.0-py3-none-any.whl
   ```

5. **Clone Hailo Model Zoo**

   ```bash
   cd ~
   git clone https://github.com/hailo-ai/hailo_model_zoo.git
   cd hailo_model_zoo
   ```

6. **Verify Installation**

   ```bash
   # Activate your environment if not done already
   cd ~/hailo_venv
   source bin/activate
   
   # Test the tools
   hailomz --help
   hailo compiler --help
   
   # Check that Python packages are installed
   pip list | grep hailo
   ```

### Recommended Workflow

For the best experience:
1. Use **native installation** if possible
2. Allocate a dedicated Ubuntu machine or partition
3. Ensure NVIDIA drivers are up to date (version 525+ for CUDA 12.x)
4. Use an SSD for faster calibration

---

## 1. Prepare Calibration Images

Hailo needs a small unlabeled image set (≈ 200–1000 images) from your dataset to calibrate the quantization step.

```bash
scp -r images_raw <USER>@<HOSTNAME>:~/hailo_ai_sw_suite/hailo_venv/
# Copy random training/validation images here
```

---

## 2. Create the yaml File

```bash
nano yolov11n_2cls.yaml
```

```text
base:
  - base/yolov8.yaml

postprocessing:
  device_pre_post_layers:
    nms: true
  hpp: true

network:
  network_name: yolov11n_2cls

paths:
  network_path:
    - /home/joe/scratch/hailo_venv/yolov11n_finetune.onnx

evaluation:
  classes: 2
  postprocess_config: /home/joe/scratch/hailo_venv/yolov11n_2cls.nms.json
```

---

## 3. Create the Model Script

The Hailo compiler needs to know the post-processing configuration.

Create `y11.alls`:

```bash
nano y11.alls
```

```text
normalization1 = normalization([0.0, 0.0, 0.0], [255.0, 255.0, 255.0])
nms_postprocess("/home/joe/scratch/hailo_venv/yolov11n_2cls.nms.json", meta_arch=yolov8, engine=cpu)
allocator_param(width_splitter_defuse=disabled)
```

---

## 4. Create the json File

```bash
nano yolov11n_2cls.nms.json
```

```text
{"nms_scores_th": 0.2, "nms_iou_th": 0.7, "image_dims": [640, 640], "max_proposals_per_class": 100, "classes": 2, "regression_length": 16, "background_removal": false, "background_removal_index": 0, "bbox_decoders": [{"name": "", "stride": 8, "reg_layer": "", "cls_layer": ""}, {"name": "", "stride": 16, "reg_layer": "", "cls_layer": ""}, {"name": "", "stride": 32, "reg_layer": "", "cls_layer": ""}]}
```

---

## 4. Run the Compilation

Activate your **Hailo-8 environment**.

```bash
hailomz compile --ckpt /home/joe/scratch/hailo_venv/yolov11n_finetune.onnx --calib-path images_raw --yaml /home/joe/scratch/hailo_venv/yolov11n_2cls.yaml --hw-arch hailo8  --model-script /home/joe/scratch/hailo_venv/y11.alls
```

### Key flags
| Option | Purpose |
|---|---|
| `--ckpt` | Path to your ONNX model |
| `--calib-path` | Directory of calibration images |
| `--yaml` | Network config (use `yolov8n.yaml` or `yolov11n.yaml` if present) |
| `--hw-arch hailo8` | Target chip (for Pi AI Hat / Hailo-8L) |
| `--model-script y11.alls` | Explicit post-processing |

After successful compilation, you’ll see:

```
Saved HAR to yolov11n.har
Saved HEF to yolov11n.hef
```

---

## 5. Deploy to Raspberry Pi AI Kit

1. Copy `yolov11n.hef` to the Pi:

   ```bash
   scp yolov11n.hef rcr@<HOSTNAME>:~
   ```

2. On the Pi, verify the device:

   ```bash
   hailortcli fw-control identify
   ```

3. Test inference:

   ```bash
   hailortcli run yolov11n.hef
   ```

For application-level use, load it with the Python or C++ `hailort` API.

---

## 6. Troubleshooting

### Environment Issues

| Symptom | Likely cause / fix |
|---|---|
| `No DNN in stream executor` or `InvalidArgumentError` with TensorFlow | CUDNN version mismatch or not installed. Check: `dpkg -l \| grep cudnn` vs `nvcc --version`. Must have matching versions (e.g., CUDNN cuda-12 for CUDA 12.x). Or use CPU mode: `export CUDA_VISIBLE_DEVICES=""` |
| `hailomz: command not found` | Activate your virtual environment: `source ~/hailo_venv/bin/activate` |
| `ImportError: cannot import name 'one_of' from 'pyparsing'` | Dependency conflict in installer environment. Use wheel-only installation (Section 5) instead of installer environment. |
| `ERROR: No matching distribution found for hailort` | HailoRT is not on PyPI. Use the wheel file from the Hailo installer. |
| `WARNING: CUDNN version should be 8.9 or higher, found ..` | Hailo installer detection issue. Verify CUDNN with `ldconfig -p \| grep cudnn`. If installed, proceed anyway. |
| `WARNING: Recommended package Node.js not found` | Using nvm instead of system-wide Node.js. Safe to ignore - nvm works fine. Verify with `node -v`. |
| `ERROR: Requirement libgraphviz-dev not found` | Install with `sudo apt install libgraphviz-dev` then re-run installer. |
| GPUs not visible in Docker | Install `nvidia-container-toolkit` and use `--gpus all` flag. Verify with `nvidia-smi` inside container. |
| `ImportError: libhailo.so` | Hailo SDK not installed or not in library path. Reinstall or check `LD_LIBRARY_PATH`. |
| Docker container exits immediately | Check Docker logs: `docker logs <container_id>`. May need to specify entrypoint or run interactively with `-it`. |
| Slow compilation without GPU | Normal. GPU acceleration speeds up optimization. Consider cloud GPU instances (AWS g4dn, GCP T4). |

### Compilation Issues

| Symptom | Likely cause / fix |
|---|---|
| ONNX has only 1 output (`output0`) instead of 6 | Model exported with `simplify=True`. Re-export with `simplify=False dynamic=False opset=11`. See Section 2. |
| `ValueError: None values not supported` during calibration | The post-process could not find reg/cls pairs — check the six output names and `y11.model`. |
| "invalid choice: 'hailo8'" | You're using the Hailo-15 SDK. Install the **Hailo-8 legacy AI Suite v3/v4**. |
| Poor accuracy | Provide ≥ 200 calibration images and use a realistic dataset. |
| No `.hef` produced | Check for earlier "Optimization" or "Statistics" exceptions; usually due to incorrect output mapping. |
| `CUDA out of memory` | Reduce batch size in calibration or use CPU mode. |
| Python version mismatch | Hailo requires Python 3.10. Use `python3.10 -m venv` to create environment. |

---

## 7. Summary

**Pipeline overview**

1. Set up Hailo development environment (native or Docker with GPU support).  
2. Fine-tune YOLOv11n with Ultralytics.  
3. Export to static ONNX.  
4. Prepare 200–1000 calibration images.  
5. Confirm 6 outputs (reg/cls pairs).  
6. Create `y11.model` for Hailo post-processing.  
7. Run `hailomz compile` with `--hw-arch hailo8`.  
8. Deploy the generated `.hef` to your Raspberry Pi AI Kit.

You now have a fully quantized and compiled YOLOv11n detector ready to run on the Hailo-8 accelerator.

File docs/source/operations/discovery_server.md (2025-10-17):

# ROS Discovery Server

The ROS discovery server facilitates communication between different ROS2 nodes. It acts as a central point for nodes to discover each other on the network.

> ⚠️ **Important**
> If you are using your robot at our Rose City Robotics Lab, a discovery server is already running on the lab network. You can skip this step if you have not yet modified this file for your home setup.

## Run your own discovery server
If you want to be able to run your robot on your own, without the RCR discovery server, you will need to follow these steps:

### Note the IP Address

`127.0.0.1` for local host (your own machine)

### Start the Discovery Server

Open a new terminal window 📟

```bash
fastdds discovery --server-id 0
```

This command initiates the Fast DDS discovery server with a server ID of 0.

### Update Configuration File

Open a new terminal window 📟

```bash
nano ~/ros2_ws/super_client_configuration_file_rcr.xml
```

```xml
<profiles xmlns="http://www.eprosima.com/XMLSchemas/fastRTPS_Profiles">
  <participant profile_name="super_client_profile" is_default_profile="true">
    <rtps>
      <builtin>
        <discovery_config>
          <discoveryProtocol>SUPER_CLIENT</discoveryProtocol>
          <discoveryServersList>
            <locator>
              <udpv4>
                <address>127.0.0.1</address>
                <port>11811</port>
              </udpv4>
            </locator>
          </discoveryServersList>
        </discovery_config>
      </builtin>
    </rtps>
  </participant>
</profiles>
```

Edit line 11 of the **`super_client_configuration_file_rcr.xml`** file to set the discovery server's address to `127.0.0.1` if running locally.

### Start the Micro ROS Agent

```bash
cd ~
SERIAL_TEENSY_DEVICE=`find /dev/serial/by-id/ -name "usb-Teensyduino*if00"|head -1`
sudo docker run -it --rm -v /dev:/dev --privileged --net=host --env-file ./env.list --name agent microros/micro-ros-agent:kilted serial --dev ${SERIAL_TEENSY_DEVICE} -v4
```

### Update DDS Configuration in Container

Open a new terminal window 📟

```bash
sudo docker cp ~/ros2_ws/super_client_configuration_file_rcr.xml agent:/uros_ws/
sudo docker commit agent microros/micro-ros-agent:kilted
```

Restart the micro ros agent after updating the configuration file inside the container (<CTRL-C> in the terminal window 📟 that is running the agent. You can use the up arrow to repeat the sudo docker run command).

### Verification

To verify the discovery server is working:

```bash
# Check if discovery server is running
ps aux | grep fastdds

# Check network connectivity
ping 127.0.0.1
```

## Switch back to RCR discovery server
If you have updated your discovery server settings above to use your robot at home, you will need to follow the steps below

### Note the IP Address

`192.168.1.125` for Joe's laptop at RCR Lab

### Update Configuration File -

Open a new terminal window 📟

```bash
nano ~/ros2_ws/super_client_configuration_file_rcr.xml
```

```xml
<profiles xmlns="http://www.eprosima.com/XMLSchemas/fastRTPS_Profiles">
  <participant profile_name="super_client_profile" is_default_profile="true">
    <rtps>
      <builtin>
        <discovery_config>
          <discoveryProtocol>SUPER_CLIENT</discoveryProtocol>
          <discoveryServersList>
            <locator>
              <udpv4>
                <address>192.168.1.125</address>
                <port>11811</port>
              </udpv4>
            </locator>
          </discoveryServersList>
        </discovery_config>
      </builtin>
    </rtps>
  </participant>
</profiles>
```

Edit line 11 of the **`super_client_configuration_file_rcr.xml`** file to set the discovery server's address to `192.168.1.125` for Joe's computer

### Start the Micro ROS Agent

```bash
cd ~
SERIAL_TEENSY_DEVICE=`find /dev/serial/by-id/ -name "usb-Teensyduino*if00"|head -1`
sudo docker run -it --rm -v /dev:/dev --privileged --net=host --env-file ./env.list --name agent microros/micro-ros-agent:kilted serial --dev ${SERIAL_TEENSY_DEVICE} -v4
```

### Update DDS Configuration in Container

Open a new terminal window 📟

```bash
sudo docker cp ~/ros2_ws/super_client_configuration_file_rcr.xml agent:/uros_ws/
sudo docker commit agent microros/micro-ros-agent:kilted
```

Restart the micro ros agent after updating the configuration file inside the container (<CTRL-C> in the terminal window 📟 that is running the agent. You can use the up arrow to repeat the sudo docker run command).

### Verification

To verify the discovery server is working:

```bash
# Check if discovery server is running
ps aux | grep fastdds

# Check network connectivity
ping 192.168.1.125
```

## Common Issues

**Discovery server not starting:**
- Check if port 11811 is available
- Verify Fast DDS is properly installed
- Check network connectivity

**Nodes not discovering each other:**
- Verify the configuration file has the correct IP address
- Check that all nodes are using the same discovery server
- Ensure firewall settings allow ROS2 communication

**Micro ROS agent connection issues:**
- Verify the Teensy device is connected
- Check the serial device path
- Ensure Docker has proper permissions

---

*For keyboard teleoperation setup, see [Keyboard Teleoperation](keyboard_teleoperation.md)*
*For troubleshooting, see [Troubleshooting](../troubleshooting/index.md)*

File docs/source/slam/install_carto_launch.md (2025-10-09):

# Install Cartographer Launch

This guide explains how to install and configure Cartographer launch files for SLAM.

## Prerequisites

Before installing Cartographer, ensure you have the latest version of the common platform repository and a ROS2 workspace set up.

## Steps

### 1. Navigate to the Repository

Change to the common platform directory:

```bash
cd ~/repos/common_platform
```

### 2. Stash Current Changes

Save any uncommitted changes:

```bash
git stash
```

### 3. Switch to Main Branch

Ensure you're on the main branch to get the latest updates:

```bash
git checkout main
```

### 4. Pull Latest Changes

Get the most recent updates from the repository:

```bash
git pull
```

### 5. Restore Stashed Changes

Apply your previously stashed changes back:

```bash
git stash pop
```

### 6. Copy Launch File

Copy the Cartographer launch file to your ROS2 workspace:

```bash
cp launch/cartographer_simple.launch.py ~/ros2_ws/src/cartographer_ros/cartographer_ros/launch/
```

### 7. Navigate to ROS2 Workspace

Change to your ROS2 workspace directory:

```bash
cd ~/ros2_ws/
```

### 8. Build Cartographer Package

Build the Cartographer ROS package with symlink installation:

```bash
colcon build --packages-select cartographer_ros --symlink-install
```

## Next Steps

After completing these steps, Cartographer should be ready to use. You can now launch SLAM mapping with the configured launch file.

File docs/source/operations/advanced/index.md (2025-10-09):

# Advanced Operations

This section covers advanced operations and configurations for the RCR Common Robotics Platform.

## Advanced Procedures

```{toctree}
:maxdepth: 1

custom_controllers
firmware_updates
performance_tuning
```

### Quick Reference
- [Custom Controllers](custom_controllers.md) - Advanced controller configuration
- [Flashing the Teensy Microcontroller](firmware_updates.md) - Flashing firmware to the Teensy
- [Performance Tuning](performance_tuning.md) - System optimization

## Advanced Overview

Advanced operations include:

1. **Custom Controllers** - Advanced control system configuration
2. **Flashing the Teensy Microcontroller** - Flashing firmware to the Teensy 4.0
3. **Performance Tuning** - System optimization
4. **Custom Development** - Advanced software development

## Prerequisites

- Basic robot operation experience
- Understanding of ROS2 concepts
- Familiarity with Linux command line
- Knowledge of robot systems

## Safety Considerations

⚠️ **Advanced operations require careful attention:**

- Always backup configurations before changes
- Test changes in safe environment
- Follow safety procedures
- Document all modifications

## Quick Reference

### Advanced Commands
```bash
# Check system configuration
ros2 param list
ros2 param get /node_name parameter_name

# Monitor system performance
ros2 run rqt_graph rqt_graph
ros2 run rqt_plot rqt_plot
```

### Development Tools
```bash
# Build custom packages
colcon build --packages-select your_package

# Test custom nodes
ros2 run your_package your_node
```

## Getting Help

For advanced operations:

1. Review documentation carefully
2. Test in safe environment
3. Contact experienced users
4. Document your modifications

---

*For basic operations, see [Setup](../setup/index.md)*
*For troubleshooting, see [Troubleshooting](../troubleshooting/index.md)*

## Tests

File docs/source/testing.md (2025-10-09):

# Testing and Validation

This section covers testing procedures for the RCR Common Robotics Platform to ensure proper functionality.

## Basic Smoke Test

The first test to perform after hardware assembly is the basic smoke test using the firmware provided in the repository.

### Prerequisites

- Hardware assembly completed
- Teensy 4.0 board properly connected
- Arduino CLI installed and configured (see [Teensy Programming Guide](../setup/teensy_programming.md))

### Running the Basic Test

**Flash the Basic Test Firmware:**
```bash
# Navigate to the firmware directory
cd ~/repos/common_platform/firmware/basic_test/

# Compile and upload the basic test
arduino-cli compile --fqbn teensy:avr:teensy40 basic_test.ino
arduino-cli upload -p /dev/ttyACM0 --fqbn teensy:avr:teensy40 basic_test.ino
```

**Expected Behavior:**
Upon successful flashing, the robot should exhibit a simple behavior pattern:
- Moving forward for a few seconds
- Pausing briefly
- Moving backward for a few seconds
- Repeating this cycle

**Verification:**
   - ✅ Robot moves forward and backward as expected
   - ✅ Motors are functioning properly
   - ✅ Basic control system is operational
   - ✅ No unusual sounds or behaviors

### Troubleshooting

If the robot doesn't move as expected:
- Check power connections
- Verify motor connections
- Ensure firmware uploaded successfully
- Check for any error messages in the serial monitor

## Additional Testing

More comprehensive testing procedures will be added to this section in future updates.

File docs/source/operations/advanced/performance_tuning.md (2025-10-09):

# Performance Tuning Guide

This guide covers advanced performance tuning techniques for the RCR Common Robotics Platform, focusing on motor calibration for straight driving and PID tuning for optimal dynamic response.

## Table of Contents

1. [Motor Calibration for Straight Driving](#motor-calibration-for-straight-driving)
2. [PID Tuning for Dynamic Response](#pid-tuning-for-dynamic-response)
3. [Serial Commands for Real-time Tuning](#serial-commands-for-real-time-tuning)
4. [Troubleshooting Common Issues](#troubleshooting-common-issues)

## Motor Calibration for Straight Driving

### Overview

Motor calibration ensures that both wheels rotate at the same speed when given identical commands, enabling the robot to drive straight. This is critical for accurate navigation and odometry.

### Prerequisites

- Robot hardware assembled and functional
- `closed_loop.ino` firmware from the add_tuning_and_odom branch uploaded to the microcontroller (see [Firmware Updates](firmware_updates.md) for upload procedure)
- Serial monitor access (115200 baud) (see [Common Issues](common_issues.md) for debug output setup)
- Level surface for testing
- Measuring tape or ruler

### Calibration Process

#### 1. Initial Setup

See [Keyboard Teleoperation Setup](KeyboardTeleop.md).

#### 2. Basic Motor Test

```bash
# Enable motor drive (You may need to send the M character multiple times to enable the motors)
M

# Test individual motors
A0.5    # Left motor at 0.5 m/s
Z0.5    # Right motor at 0.5 m/s

# Stop motors
M
```

#### 3. Straight Line Test

1. **Mark Starting Position**
   - Place robot on level surface
   - Mark starting position with tape
   - Ensure robot is facing straight ahead

2. **Run Straight Test**
   ```bash
   # Reset odometry
   X

   # Drive forward at moderate speed
   ↑ (Up Arrow)
   ```

3. **Measure Deviation**
   - Measure how far the robot deviated from straight line
   - Record the deviation distance and direction

#### 4. Coarse-tuning Parameters

**Motor Scale Adjustment (Recommended First)**
```bash
# If robot drifts left, increase right motor scale
N1.1     # Increase right motor scale to 1.1

# If robot drifts right, increase left motor scale
B1.1     # Increase left motor scale to 1.1
```

## PID Tuning for Dynamic Response

### Overview

PID (Proportional-Integral-Derivative) controllers regulate motor speed to match target velocities. Proper tuning ensures:
- Fast response to speed changes
- Minimal overshoot
- Steady-state accuracy
- Stability under load

### PID Parameters

#### Proportional (P) Gain
- **Effect**: Immediate response to error
- **Too High**: Oscillations, instability
- **Too Low**: Slow response, steady-state error
- **Default**: 8.0

#### Integral (I) Gain
- **Effect**: Eliminates steady-state error
- **Too High**: Oscillations, windup
- **Too Low**: Persistent error
- **Default**: 0.8

#### Derivative (D) Gain
- **Effect**: Damping, reduces overshoot
- **Too High**: Noise sensitivity, instability
- **Too Low**: Overshoot, oscillations
- **Default**: 0.0 (disabled)

### Tuning Methodology

#### 1. Start with P-Only Control

```bash
# Reset PID parameters
X

# Set P gain only
Q5.0     # Left motor P=5.0
U5.0     # Right motor P=5.0
W0.0     # Disable left integral
O0.0     # Disable right integral
E0.0     # Disable left derivative
T0.0     # Disable right derivative
```

#### 2. Test Response

```bash
# Test step response
S0.5     # Test both motors at 0.5 m/s
```

**Observe:**
- Rise time (time to reach target)
- Overshoot (maximum error)
- Steady-state error
- Oscillations

#### 3. Adjust P Gain

**If too slow/steady-state error:**
```bash
Q6.0     # Increase left P gain
U6.0     # Increase right P gain
```

**If oscillating:**
```bash
Q4.0     # Decrease left P gain
U4.0     # Decrease right P gain
```

#### 4. Add Integral Control

Once P gain is stable:

```bash
W0.5     # Add small left I gain
O0.5     # Add small right I gain
```

**Test for:**
- Elimination of steady-state error
- No oscillations
- Smooth response

#### 5. Add Derivative Control (Optional)

For systems with overshoot:

```bash
E0.1     # Small left D gain
T0.1     # Small right D gain
```

**Monitor for:**
- Reduced overshoot
- No noise amplification
- Stable response

### Advanced Tuning Techniques

#### 1. Ziegler-Nichols Method

1. **Find Ultimate Gain (Ku)**
   - Start with P=1.0, I=0, D=0
   - Increase P until sustained oscillations
   - Record Ku and oscillation period Tu

2. **Calculate Parameters**
   - P = 0.6 × Ku
   - I = 2 × P / Tu
   - D = P × Tu / 8

#### 2. Load-Dependent Tuning

Test under different load conditions:

```bash
# Light load (no payload)
F1.0

# Heavy load (with payload)
F1.0
```

Adjust gains for consistent performance across load ranges.

#### 3. Speed-Dependent Tuning

Test at different speeds:

```bash
# Low speed
F0.2

# Medium speed
F0.5

# High speed
F1.0
```

### Performance Metrics

#### 1. Response Time
- **Target**: < 0.5 seconds to reach 95% of target speed
- **Measurement**: Monitor speed feedback via serial output

#### 2. Steady-State Error
- **Target**: < 2% of target speed
- **Measurement**: Compare target vs actual speed

#### 3. Overshoot
- **Target**: < 10% of target speed
- **Measurement**: Peak speed during step response

#### 4. Settling Time
- **Target**: < 1 second to settle within 5% of target
- **Measurement**: Time to reach and stay within error band

## Serial Commands for Real-time Tuning

The `closed_loop.ino` firmware provides serial commands for real-time parameter adjustment:

### Basic Commands

| Command | Description | Example |
|---|---|---|
| `M` | Toggle motor drive on/off | `M` |
| `X` | Reset all state | `X` |
| `H` | Show help with all commands | `H` |

### Motor Testing Commands

| Command | Description | Example |
|---|---|---|
| `S<speed>` | Test both motors at same speed | `S0.5` |
| `A<speed>` | Test left motor only | `A0.5` |
| `Z<speed>` | Test right motor only | `Z0.5` |

### Motor Scale Commands

| Command | Description | Example |
|---|---|---|
| `B<scale>` | Set left motor scale (0.5-2.0) | `B1.1` |
| `N<scale>` | Set right motor scale (0.5-2.0) | `N0.9` |

### PID Tuning Commands

| Command | Description | Example |
|---|---|---|
| `Q<value>` | Set left motor PID P | `Q8.0` |
| `W<value>` | Set left motor PID I | `W0.8` |
| `E<value>` | Set left motor PID D | `E0.1` |
| `U<value>` | Set right motor PID P | `U8.0` |
| `O<value>` | Set right motor PID I | `O0.8` |
| `T<value>` | Set right motor PID D | `T0.1` |

### Parameter Management Commands

| Command | Description | Example |
|---|---|---|
| `Y` | Save tuning to EEPROM | `Y` |
| `G` | Load tuning from EEPROM | `G` |
| `C` | Reset tuning to defaults | `C` |

### Monitoring Commands

Enable debug output to monitor performance:

```cpp
// In the setup.h header for closed_loop.ino, set debug levels:
#define PRINT_MOVES 2    // Enable status updates
#define PRINT_PID 1      // Enable PID debug output
```

### Adjust the maximum allowed speed

```cpp
// In the motor control header MotorControl.h, set the maximum PWM allowed:
static constexpr int MAX_PWM = 120; // Limit PWM magnitude (0-255) on or around line 46
```

Recompile the firmware and upload after changing PRINT_MOVES or MAX_PWM (see [Firmware Updates](firmware_updates.md) for procedure).

###

## Troubleshooting Common Issues

### 1. Robot Won't Drive Straight

**Symptoms:**
- Consistent drift in one direction
- Uneven wheel speeds

**Solutions:**
- Verify encoder connections
- Calibrate individual motor PWM scaling factors
- Check for mechanical binding

### 2. Oscillations/Instability

**Symptoms:**
- Motor speed oscillates around target
- Robot shakes or vibrates

**Solutions:**
- Reduce P gain
- Add derivative control
- Check for mechanical issues
- Verify encoder noise

### 3. Slow Response

**Symptoms:**
- Takes too long to reach target speed
- Sluggish acceleration

**Solutions:**
- Increase P gain
- Add integral control
- Check for mechanical friction
- Verify power supply

### 4. Steady-State Error

**Symptoms:**
- Robot doesn't reach target speed
- Persistent speed error

**Solutions:**
- Increase I gain
- Check for load variations
- Verify target speed calculations
- Check for mechanical binding

### 5. Noise Sensitivity

**Symptoms:**
- Erratic behavior with small changes
- Sensitive to disturbances

**Solutions:**
- Reduce D gain
- Add filtering
- Check encoder connections
- Improve mechanical isolation

### 6. Motor Stall

**Symptoms:**
- High-pitched whining or squealing sound from motors
- Motors not responding to commands
- Can cause motors to heat up due to current not producing useful work

**Solutions:**
- P gain too high causing oscillations, reduce P gain
- Mechanical binding or obstruction, inspect wheels
- Insufficient power supply, check battery voltage, charge if necessary
- Inadequate PWM scaling, adjust calibration

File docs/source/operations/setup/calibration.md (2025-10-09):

# Calibration Procedures

This guide covers the calibration procedures for sensors and systems on the RCR Common Robotics Platform.

## Prerequisites

- Hardware and software setup completed
- Robot in a stable, level environment
- Calibration tools (ruler, level, etc.)
- Access to robot console/terminal

## IMU Calibration

### 1. Static Calibration

```bash
# Launch robot with IMU
ros2 launch common_platform launch_robot.launch.py

# Monitor IMU data
ros2 topic echo /${ROS_NAME}/imu/data
```

### 2. Calibration Steps

1. **Level the Robot**
   - Place robot on level surface
   - Ensure no movement during calibration

2. **Run Calibration**
   ```bash
   # Use calibration tool
   ros2 run imu_calibration calibrate_imu
   ```

3. **Verify Results**
   - Check for zero bias values
   - Verify stable readings

## LiDAR Calibration

### 1. Mounting Verification

- Ensure LiDAR is level
- Check for obstructions
- Verify mounting stability

### 2. Range Calibration

```bash
# Monitor LiDAR data
ros2 topic echo /${ROS_NAME}/scan

# Check for consistent readings
ros2 run rqt_plot rqt_plot /${ROS_NAME}/scan/ranges
```

### 3. Angular Calibration

- Verify 360° coverage
- Check for blind spots
- Test at different distances

## Camera Calibration

### 1. Intrinsic Calibration

```bash
# Launch camera
ros2 launch common_platform camera.launch.py

# Run calibration
ros2 run camera_calibration cameracalibrator --size 8x6 --square 0.108 image:=/camera/image_raw camera:=/camera
```

### 2. Extrinsic Calibration

- Align camera with robot frame
- Verify coordinate transformations
- Test with known objects

## Motor Calibration

### 1. Encoder Calibration

```bash
# Test encoder counts
ros2 topic echo /${ROS_NAME}/wheel_odom

# Verify counts per revolution
ros2 run motor_calibration calibrate_encoders
```

### 2. PID Tuning

```bash
# Launch motor control
ros2 launch common_platform motor_control.launch.py

# Tune PID parameters
ros2 run rqt_reconfigure rqt_reconfigure
```

## Odometry Calibration

### 1. Wheel Diameter

- Measure actual wheel diameter
- Update configuration parameters
- Test with known distances

### 2. Wheelbase

- Measure distance between wheels
- Update robot description
- Verify turning radius

## System Integration

### 1. Coordinate Frames

```bash
# Check transform tree
ros2 run tf2_tools view_frames

# Verify frame relationships
ros2 run tf2_ros tf2_echo base_link laser_link
```

### 2. Sensor Fusion

- Verify sensor data alignment
- Check for timing issues
- Test data consistency

## Calibration Verification

### 1. Static Tests

- Robot should report zero velocity when stationary
- IMU should show level orientation
- LiDAR should show consistent environment

### 2. Dynamic Tests

- Move robot known distances
- Verify odometry accuracy
- Test sensor data during movement

## Troubleshooting

### Common Issues

**IMU Drift**
- Check mounting stability
- Verify calibration parameters
- Consider temperature effects

**LiDAR Inconsistencies**
- Check for obstructions
- Verify mounting alignment
- Test in different environments

**Odometry Errors**
- Verify encoder connections
- Check wheel diameter measurements
- Test on different surfaces

## Maintenance

### Regular Calibration

- Monthly IMU calibration
- Quarterly LiDAR verification
- Annual full system calibration

### Documentation

- Record calibration values
- Note environmental conditions
- Track performance over time

---

*For hardware setup, see [Hardware Setup](hardware_setup.md)*
*For software setup, see [Software Setup](software_setup.md)*
*For troubleshooting, see [Troubleshooting](../troubleshooting/index.md)*

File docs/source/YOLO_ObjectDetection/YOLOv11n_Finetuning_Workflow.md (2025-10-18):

# YOLOv11n Fine-Tuning Workflow (Ultralytics on macOS)

This guide documents the full process used to fine-tune a **YOLOv11n** object-detection model using custom data labeled in **Label Studio**.
**Note that the following steps are best performmed on a computer with a good GPU and plenty of memory. Not the Raspberry Pi 5!**

---

## 0. [Data Labeling with Label Studio](../data_annotation/label_studio.md)

Each exported JSON (e.g., `annotations/999`) contains fields like:

```json
{
  "id": 999,
  "result": [],
  "created_username": "",
  "created_ago": "0\u00a0minutes",
  "completed_by": {
    "id": 1,
    "first_name": "",
    "last_name": "",
    "email": ""
  },
  "task": {
    "id": 999,
    "data": {
      "image": "/data/local-files/?d=home/rcr/teleop_data/images/00011190.jpg"
    },
    "meta": {},
    "created_at": "2025-10-08T23:41:28.798109Z",
    "updated_at": "2025-10-08T23:41:28.798143Z",
    "is_labeled": true,
    "overlap": 1,
    "inner_id": 999,
    "total_annotations": 1,
    "cancelled_annotations": 0,
    "total_predictions": 0,
    "comment_count": 0,
    "unresolved_comment_count": 0,
    "last_comment_updated_at": null,
    "project": 1,
    "updated_by": null,
    "file_upload": null,
    "comment_authors": []
  },
  "was_cancelled": false,
  "ground_truth": false,
  "created_at": "2025-10-09T00:08:55.627074Z",
  "updated_at": "2025-10-09T00:08:55.627108Z",
  "draft_created_at": null,
  "lead_time": 0.666,
  "import_id": null,
  "last_action": null,
  "bulk_created": false,
  "project": 1,
  "updated_by": 1,
  "parent_prediction": null,
  "parent_annotation": null,
  "last_created_by": null
}
```

---

## 1. Create the directory structure for fine tuning

You will need a python virtual environment in which to install and use the Ultralytics software for fine tuning the YOLO model.

```bash
cd
python3 -m venv finetune
cd finetune
source bin/activate
mkdir scripts
cp ~/repos/common_platform/scripts/ls_to_yolo.py scripts/
cp ~/repos/common_platform/scripts/make_split_and_yaml.py scripts/
cp ~/repos/common_platform/scripts/prune_images_without_boxes.py scripts/
mkdir -p data/images_raw
cp ~/teleop_data/images/* data/images_raw/
cp -r ~/teleop_data/annotations data/
mkdir models
cp ~/code/common_platform/models/yolo11n.pt models/
mkdir runs
pip install ultralytics
```

---

## 2. Convert Label Studio JSON to YOLO Format

Label Studio’s JSON format must be converted into YOLO-style text files.

A conversion script `ls_to_yolo.py` was used:

```bash
python3 scripts/ls_to_yolo.py
```

Output example:

```
Converted items: 1504
Class mapping: {0: 'Purple ball', 1: 'Green ball'}
Paste this into data.yaml as names: ['Purple ball', 'Green ball']
Stats: {'total_items': 1504, 'with_any_result': 271, 'with_boxes': 271, 'images_copied': 1504, 'missing_images': 0, 'empty_results': 1233}
```

Then, split the data into training and validation sets
```bash
python3 scripts/make_split_and_yaml.py
```

This script created:
- YOLO-formatted label `.txt` files (one per image)
- a **data split** structure:
  ```
  data/
  ├── images/train/
  ├── images/val/
  ├── labels/train/
  ├── labels/val/
  ```

Finally, update the data.yaml

---

## 3. Clean Up the Dataset

A secondary script removed images with **no bounding boxes**:

```bash
python3 scripts/prune_images_without_boxes.py --images-dir data/images_raw --annotations-dir data/annotations --delete
```

Result:

```
Found 271 stems with rectangles.
Images scanned: 1504  |  keep: 271  |  prune: 1233
```

After pruning, only labeled images remained in `data/images_raw/`. This is necessary to create a calibration dataset for the conversion to the .hef format that will work on the Hailo 8 AI Hat.

---

## 4. Edit the `data.yaml` File

The `data.yaml` file was created by `make_split_and_yaml.py`. It describes the dataset and class names:

```yaml
path: data
train: train/images
val: val/images
nc: 2
names:
- class_0
- class_1
```

**Edit the `data.yaml` file with the correct class names.**
```bash
nano data.yaml
```

```
names:
- Purple ball
- Green ball
```

---

## 5. Verify Ultralytics Installation

You can test on a sample dataset to confirm everything works:

```bash
yolo detect train model=yolo11n.pt data=coco8.yaml epochs=1 imgsz=640
```

---

## 6. Fine-Tune the YOLOv11n Model

**Note that this will take a VERY LONG time on the Raspberry Pi 5. It is better to run it on a computer with a good GPU and lots of memory.**
Run training on your custom data:

```bash
yolo train model=models/yolo11n.pt data=data.yaml epochs=100 imgsz=640 batch=16 project=runs name=y11n_finetune
```

Choosing a batch size
| Hardware | Recommended batch |
| --- | --- |
| **M1 / M2 / M3 MacBook Air** | `batch=8` |
| **M1 / M2 / M3 Pro (16 GB)** | `batch=16` |
| **M1 / M2 / M3 Max (32–64 GB)** | `batch=32` |
| **Intel Mac (CPU only)** | `batch=4` (or even `2`) |

Key arguments:
| Option | Description |
|---|---|
| `model=yolo11n.pt` | Base pretrained YOLOv11n weights |
| `data=data.yaml` | Custom dataset definition |
| `epochs=100` | Train for 100 epochs |
| `imgsz=640` | Input image size |
| `batch=16` | Batch size (adjust to available RAM) |
| `device=mps` | **Add this if on Apple Silicon Mac to use Metal GPU acceleration** |
| `project=runs` | Output directory |
| `name=y11n_custom` | Experiment name |

---

## 7. Monitor Training Progress

During training, YOLO prints metrics per epoch:

| Metric | Meaning |
|---|---|
| `box_loss` | Bounding-box regression error |
| `cls_loss` | Classification loss |
| `dfl_loss` | Distribution Focal Loss (for box boundaries) |
| `Instances` | Number of labeled objects in batch |

Validation metrics (computed every few epochs):
- **Precision** – fraction of predicted boxes that are correct.
- **Recall** – fraction of ground truths correctly detected.
- **mAP@50** – mean average precision at IoU ≥ 0.50.
- **mAP@50-95** – stricter average over IoU 0.50–0.95.

---

## 8. Results and Best Model

After 100 epochs, YOLO saves results in:

```
runs/train/y11n_finetune/
├── weights/
│   ├── best.pt
│   └── last.pt
├── results.csv
└── confusion_matrix.png
```

Use `best.pt` for inference or export.

---

## 9. Export the Model for Hailo Deployment

```bash
cd runs/y11n_finetune/weights
yolo export model=best.pt format=onnx imgsz=640 simplify=True nms=False
mv best.onnx yolov11n_finetune.onnx
scp yolov11n_finetune.onnx <USER>@<HOSTNAME>:~
```

---

## 10. Summary

| Stage | Purpose | Tool |
|---|---|---|
| Label images | Create bounding-box annotations | Label Studio |
| Convert annotations | JSON → YOLO format | `ls_to_yolo.py` |
| Prune dataset | Remove unlabeled images | `prune_images_without_boxes.py` |
| Fine-tune | Train YOLOv11n on 2 classes | Ultralytics YOLO |
| Export | Produce ONNX for Hailo | `yolo export` |

Final output:
✅ `best.pt` (PyTorch weights)
✅ `yolov11n_finetune.onnx` (for hardware deployment)

---

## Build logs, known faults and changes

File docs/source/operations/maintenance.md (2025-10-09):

# Routine Maintenance

This guide covers regular maintenance procedures for the RCR Common Robotics Platform.

## Maintenance Schedule

### Daily Maintenance
- Visual inspection
- Sensor cleaning
- Connection check

### Weekly Maintenance
- Battery check
- System test
- Log review

### Monthly Maintenance
- Full system inspection
- Calibration check
- Performance review

### Quarterly Maintenance
- Deep cleaning
- Component replacement
- Software updates

## Daily Maintenance

### 1. Visual Inspection

**Check for Damage**
- Inspect chassis for cracks or damage
- Check wheels for wear or damage
- Look for loose screws or bolts
- Verify sensor mounting

**Connection Check**
- Ensure all cables are secure
- Check for damaged cables
- Verify power connections
- Test USB connections

### 2. Sensor Cleaning

**LiDAR Cleaning**
```bash
# Power off robot first
# Clean LiDAR lens with soft cloth
# Remove any obstructions
# Check for scratches or damage
```

**Camera Cleaning**
- Clean camera lens
- Remove dust and debris
- Check for condensation
- Verify clear view

**IMU Cleaning**
- Clean mounting surface
- Check for vibration
- Verify secure mounting

### 3. System Check

**Power System**
```bash
# Check battery voltage
# Verify power indicators
# Test power switch
# Check for loose connections
```

**Communication Test**
```bash
# Test USB connections
# Verify serial communication
# Check network connectivity
```

## Weekly Maintenance

### 1. Battery Maintenance

**Voltage Check**
- Measure battery voltage
- Check for voltage drop under load
- Verify charging system
- Test battery capacity

**Battery Care**
- Clean battery terminals
- Check for corrosion
- Verify proper storage
- Monitor charging cycles

### 2. System Testing

**Full System Test**
```bash
# Launch robot system
ros2 launch common_platform launch_robot.launch.py

# Test all sensors
ros2 topic echo /${ROS_NAME}/scan
ros2 topic echo /${ROS_NAME}/camera/image_raw
ros2 topic echo /${ROS_NAME}/imu/data

# Test motor system
ros2 topic pub /cmd_vel geometry_msgs/msg/Twist "{}"
```

**Performance Check**
- Monitor system performance
- Check for errors
- Verify response times
- Test navigation capabilities

### 3. Log Review

**System Logs**
```bash
# Check system logs
journalctl -u ros2

# Review error logs
grep -i error /var/log/syslog

# Check ROS2 logs
ros2 log list
```

## Monthly Maintenance

### 1. Full System Inspection

**Hardware Inspection**
- Complete visual inspection
- Check all mounting points
- Verify component alignment
- Test all connections

**Software Inspection**
- Check for updates
- Verify configuration files
- Review performance metrics
- Test all functionality

### 2. Calibration Check

**Sensor Calibration**
- Verify IMU calibration
- Check LiDAR alignment
- Test camera calibration
- Verify odometry accuracy

**System Calibration**
- Test motor performance
- Check encoder accuracy
- Verify sensor fusion
- Test navigation accuracy

### 3. Performance Review

**Metrics Collection**
- Document performance data
- Track error rates
- Monitor battery life
- Record maintenance issues

## Quarterly Maintenance

### 1. Deep Cleaning

**Complete Disassembly**
- Remove all sensors
- Clean all components
- Check for wear
- Replace worn parts

**Reassembly**
- Reassemble with care
- Verify all connections
- Test all systems
- Update documentation

### 2. Component Replacement

**Wear Items**
- Replace worn wheels
- Update filters
- Check bearings
- Replace cables if needed

**Preventive Replacement**
- Replace aging components
- Update firmware
- Check for recalls
- Plan upgrades

### 3. Software Updates

**System Updates**
```bash
# Update system packages
sudo apt update && sudo apt upgrade

# Update ROS2 packages
rosdep update
rosdep install --from-paths src --ignore-src -r -y

# Rebuild workspace
colcon build
```

**Firmware Updates**
- Check for firmware updates
- Update robot firmware
- Update sensor firmware
- Test all updates

## Maintenance Records

### Documentation

**Maintenance Log**
- Date and time
- Performed tasks
- Issues found
- Parts replaced
- Next maintenance due

**Performance Log**
- System performance
- Error rates
- Battery life
- Usage statistics

### Tracking

**Maintenance Schedule**
- Track maintenance intervals
- Plan future maintenance
- Order parts in advance
- Schedule downtime

## Troubleshooting

### Common Issues

**Battery Problems**
- Check voltage levels
- Verify charging system
- Test under load
- Replace if necessary

**Sensor Issues**
- Clean sensors
- Check connections
- Verify calibration
- Test individually

**Communication Problems**
- Check cables
- Verify connections
- Test communication
- Replace if needed

## Safety During Maintenance

### Safety Guidelines

- Always power off before maintenance
- Use appropriate tools
- Follow safety procedures
- Document all work

### Emergency Procedures

- Know emergency contacts
- Have backup plans
- Keep spare parts
- Document procedures

---

*For startup procedures, see [Startup Procedure](startup_procedure.md)*
*For shutdown procedures, see [Shutdown Procedure](shutdown_procedure.md)*
*For troubleshooting, see [Troubleshooting](../troubleshooting/index.md)*

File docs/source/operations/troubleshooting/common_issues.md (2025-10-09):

# Common Issues and Solutions

This document addresses frequently encountered problems with the RCR Common Robotics Platform and their solutions.

## Communication with Teensy 4.0 Microcontroller
**View debug output**
   ```bash
   SERIAL_TEENSY_DEVICE=`find /dev/serial/by-id/ -name "usb-Teensyduino*if02"|head -1`
   python3 -m serial.tools.miniterm ${SERIAL_TEENSY_DEVICE} 115200
   ```

## Power Issues

### Robot Won't Power On

**Symptoms:**
- No LED indicators
- No response to power switch
- Dead system

**Possible Causes & Solutions:**

1. **Battery Issues**
   - **Cause**: Dead or low battery
   - **Solution**: Check battery voltage, charge if needed
   - **Prevention**: Regular battery maintenance

2. **Power Switch Failure**
   - **Cause**: Faulty power switch
   - **Solution**: Test switch continuity, replace if needed
   - **Prevention**: Handle switch gently

3. **Loose Connections**
   - **Cause**: Poor battery connections
   - **Solution**: Check and tighten all power connections
   - **Prevention**: Regular connection inspection

### Intermittent Power Loss

**Symptoms:**
- Robot shuts down unexpectedly
- System resets during operation
- Unstable power indicators

**Solutions:**
1. Check battery voltage under load
2. Inspect power cables for damage
3. Verify power distribution board connections
4. Test with known good battery

## Communication Issues

### ROS2 Nodes Not Starting

**Symptoms:**
- Missing nodes in `ros2 node list`
- Launch failures
- Communication timeouts

**Solutions:**

1. **Network Issues**
   ```bash
   # Check network connectivity
   ping <robot_ip>

   # Verify ROS2 environment
   echo $ROS_DOMAIN_ID
   ```

2. **Launch File Problems**
   ```bash
   # Test launch file syntax
   ros2 launch --dry-run common_platform launch_robot.launch.py
   ```

3. **Dependency Issues**
   ```bash
   # Check for missing packages
   rosdep check --from-paths src --ignore-src
   ```

### Sensor Communication Errors

**Symptoms:**
- No sensor data on topics
- Error messages about sensor connections
- Inconsistent sensor readings

**Solutions:**

1. **USB Connection Issues**
   - Check USB cable integrity
   - Try different USB ports
   - Verify device permissions

2. **Serial Communication Problems**
   - Check baud rate settings
   - Verify serial port assignments
   - Test with serial terminal

3. **I2C Bus Issues**
   - Check I2C device addresses
   - Verify pull-up resistors
   - Test I2C bus with tools

## Navigation Issues

### Localization Problems

**Symptoms:**
- Robot loses position
- Incorrect pose estimates
- Navigation failures

**Solutions:**

1. **Map Issues**
   - Verify map file integrity
   - Check map resolution and origin
   - Reload map if corrupted

2. **Sensor Data Quality**
   - Check LiDAR data quality
   - Verify IMU calibration
   - Clean sensor surfaces

3. **Algorithm Parameters**
   - Tune localization parameters
   - Adjust particle filter settings
   - Review AMCL configuration

### Path Planning Failures

**Symptoms:**
- No valid paths found
- Robot gets stuck
- Inefficient path planning

**Solutions:**

1. **Costmap Issues**
   - Check obstacle detection
   - Verify inflation parameters
   - Review costmap layers

2. **Goal Issues**
   - Ensure goal is reachable
   - Check goal tolerance settings
   - Verify coordinate frames

## Motor and Movement Issues

### Motors Not Responding

**Symptoms:**
- No movement on command
- Motors make noise but don't move
- Uneven motor performance

**Solutions:**

1. **Motor Driver Issues**
   - Check motor driver connections
   - Verify driver power supply
   - Test driver functionality

2. **Encoder Problems**
   - Check encoder wiring
   - Verify encoder counts
   - Test encoder resolution

3. **Control Loop Issues**
   - Check PID parameters
   - Verify control loop timing
   - Review motor specifications

### Uneven Movement

**Symptoms:**
- Robot drifts to one side
- Uneven wheel speeds
- Curved movement when going straight

**Solutions:**

1. **Calibration Issues**
   - Recalibrate wheel diameters
   - Check wheelbase measurements
   - Verify encoder counts per revolution

2. **Mechanical Issues**
   - Check wheel alignment
   - Verify tire pressure
   - Inspect for mechanical binding

## Diagnostic Commands

### System Health Check
```bash
# Check system resources
htop

# Check disk space
df -h

# Check network connectivity
ip addr show
```

### ROS2 Diagnostics
```bash
# List all nodes
ros2 node list

# Check topic rates
ros2 topic hz /${ROS_NAME}/topic_name

# Monitor system performance
ros2 run rqt_graph rqt_graph
```

### Hardware Diagnostics
```bash
# Check USB devices
lsusb

# Check serial devices
ls /dev/tty*

# Check I2C devices
i2cdetect -y 1
```

## When to Seek Help

Contact the PARTS team if:

- Issues persist after trying solutions
- Hardware appears damaged
- Error messages are unclear
- System behavior is dangerous

## Prevention Tips

1. **Regular Maintenance**
   - Clean sensors regularly
   - Check connections monthly
   - Update software regularly

2. **Proper Operation**
   - Follow startup/shutdown procedures
   - Use appropriate operating environments
   - Monitor system during operation

3. **Documentation**
   - Keep logs of issues and solutions
   - Document any modifications
   - Share solutions with community

---

*For more detailed troubleshooting, see [Recovery Procedures](recovery_procedures.md)*
*For error code reference, see [Error Codes](error_codes.md)*

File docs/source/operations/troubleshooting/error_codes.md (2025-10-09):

# Error Codes Reference

This document provides a reference for error codes and messages that may appear in the RCR Common Robotics Platform.

## ROS2 Error Codes

### Node Errors

**Node Not Found**
- **Code**: `NODE_NOT_FOUND`
- **Cause**: Node not running or not found
- **Solution**: Check if node is launched, verify node name

**Node Already Running**
- **Code**: `NODE_ALREADY_RUNNING`
- **Cause**: Multiple instances of same node
- **Solution**: Kill existing node, restart system

### Topic Errors

**Topic Not Found**
- **Code**: `TOPIC_NOT_FOUND`
- **Cause**: Topic not published or wrong name
- **Solution**: Check topic list, verify publisher

**Topic Connection Failed**
- **Code**: `TOPIC_CONNECTION_FAILED`
- **Cause**: Network or communication issue
- **Solution**: Check network, restart nodes

### Service Errors

**Service Not Available**
- **Code**: `SERVICE_NOT_AVAILABLE`
- **Cause**: Service not running or not found
- **Solution**: Check service list, verify service name

**Service Call Failed**
- **Code**: `SERVICE_CALL_FAILED`
- **Cause**: Service error or timeout
- **Solution**: Check service logs, verify parameters

## Hardware Error Codes

### Power System Errors

**Low Battery**
- **Code**: `LOW_BATTERY`
- **Cause**: Battery voltage below threshold
- **Solution**: Charge battery, check battery health

**Power Supply Failure**
- **Code**: `POWER_SUPPLY_FAILURE`
- **Cause**: Power supply malfunction
- **Solution**: Check power connections, replace supply

**Overcurrent Protection**
- **Code**: `OVERCURRENT_PROTECTION`
- **Cause**: Current draw too high
- **Solution**: Check for shorts, reduce load

### Motor System Errors

**Motor Driver Error**
- **Code**: `MOTOR_DRIVER_ERROR`
- **Cause**: Motor driver malfunction
- **Solution**: Check driver connections, replace driver

**Encoder Error**
- **Code**: `ENCODER_ERROR`
- **Cause**: Encoder malfunction or disconnection
- **Solution**: Check encoder wiring, replace encoder

**Motor Overload**
- **Code**: `MOTOR_OVERLOAD`
- **Cause**: Motor current too high
- **Solution**: Reduce load, check for binding

### Sensor Errors

**LiDAR Error**
- **Code**: `LIDAR_ERROR`
- **Cause**: LiDAR malfunction or disconnection
- **Solution**: Check USB connection, restart LiDAR

**Camera Error**
- **Code**: `CAMERA_ERROR`
- **Cause**: Camera malfunction or disconnection
- **Solution**: Check USB connection, restart camera

**IMU Error**
- **Code**: `IMU_ERROR`
- **Cause**: IMU malfunction or disconnection
- **Solution**: Check I2C connection, restart IMU

## Navigation Error Codes

### Localization Errors

**Localization Lost**
- **Code**: `LOCALIZATION_LOST`
- **Cause**: Robot lost position in map
- **Solution**: Set initial pose, check sensor data

**Poor Localization**
- **Code**: `POOR_LOCALIZATION`
- **Cause**: Low localization confidence
- **Solution**: Improve sensor data, tune parameters

### Path Planning Errors

**No Path Found**
- **Code**: `NO_PATH_FOUND`
- **Cause**: No valid path to goal
- **Solution**: Check goal accessibility, adjust parameters

**Path Planning Failed**
- **Code**: `PATH_PLANNING_FAILED`
- **Cause**: Path planning algorithm error
- **Solution**: Check costmap, restart planner

### Navigation Errors

**Navigation Failed**
- **Code**: `NAVIGATION_FAILED`
- **Cause**: Navigation system error
- **Solution**: Check localization, restart navigation

**Goal Unreachable**
- **Code**: `GOAL_UNREACHABLE`
- **Cause**: Goal location not accessible
- **Solution**: Set different goal, check obstacles

## System Error Codes

### Communication Errors

**Serial Communication Error**
- **Code**: `SERIAL_COMM_ERROR`
- **Cause**: Serial port communication failure
- **Solution**: Check serial connection, restart device

**USB Communication Error**
- **Code**: `USB_COMM_ERROR`
- **Cause**: USB communication failure
- **Solution**: Check USB connection, restart device

**Network Communication Error**
- **Code**: `NETWORK_COMM_ERROR`
- **Cause**: Network communication failure
- **Solution**: Check network connection, restart network

### File System Errors

**File Not Found**
- **Code**: `FILE_NOT_FOUND`
- **Cause**: Required file missing
- **Solution**: Check file path, restore file

**Permission Denied**
- **Code**: `PERMISSION_DENIED`
- **Cause**: Insufficient permissions
- **Solution**: Check file permissions, use sudo if needed

**Disk Space Full**
- **Code**: `DISK_SPACE_FULL`
- **Cause**: Insufficient disk space
- **Solution**: Free up disk space, clean logs

## Error Handling

### Error Logging

**System Logs**
```bash
# Check system logs
journalctl -u ros2
journalctl -u robot

# Check ROS2 logs
ros2 log list
ros2 log show
```

**Application Logs**
```bash
# Check application logs
tail -f /var/log/robot.log
tail -f ~/.ros/log/latest/robot.log
```

### Error Recovery

**Automatic Recovery**
- System attempts automatic recovery
- Restart failed components
- Fallback to safe mode

**Manual Recovery**
- Follow recovery procedures
- Restart system components
- Check error logs

### Error Prevention

**Regular Maintenance**
- Perform regular maintenance
- Monitor system health
- Update software regularly

**Monitoring**
- Monitor system performance
- Check for early warning signs
- Implement health checks

## Diagnostic Tools

### System Diagnostics
```bash
# Check system resources
htop
df -h
free -h

# Check network
ip addr show
ping google.com

# Check USB devices
lsusb
ls /dev/tty*
```

### ROS2 Diagnostics
```bash
# Check ROS2 status
ros2 node list
ros2 topic list
ros2 service list

# Monitor topics
ros2 topic hz /${ROS_NAME}/topic_name
ros2 topic echo /${ROS_NAME}/topic_name
```

### Hardware Diagnostics
```bash
# Check I2C devices
i2cdetect -y 1

# Check serial devices
ls /dev/tty*

# Check power
cat /sys/class/power_supply/BAT0/voltage_now
```

## Error Reporting

### Reporting Errors

When reporting errors, include:

1. **Error Code**: Specific error code
2. **Error Message**: Full error message
3. **Context**: What was happening when error occurred
4. **System State**: Current system state
5. **Logs**: Relevant log entries
6. **Steps to Reproduce**: How to reproduce the error

### Error Tracking

- Document all errors
- Track error frequency
- Monitor error trends
- Update error codes as needed

---

*For common issues, see [Common Issues](common_issues.md)*
*For recovery procedures, see [Recovery Procedures](recovery_procedures.md)*
*For troubleshooting, see [Troubleshooting](../troubleshooting/index.md)*

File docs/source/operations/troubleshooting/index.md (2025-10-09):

# Troubleshooting

This section provides comprehensive troubleshooting guides for the RCR Common Robotics Platform.

## Troubleshooting Guides

### Common Issues
- [Common Issues](common_issues.md) - Frequently encountered problems and solutions

### Error Reference
- [Error Codes](error_codes.md) - Error code reference and meanings

### Recovery Procedures
- [Recovery Procedures](recovery_procedures.md) - System recovery and repair procedures

## Quick Troubleshooting

### System Status Check
```bash
# Check system status
ros2 node list
ros2 topic list
ros2 service list

# Check for errors
ros2 log list
journalctl -u ros2
```

### Common Commands
```bash
# Restart robot system
ros2 launch common_platform launch_robot.launch.py

# Check sensor data
ros2 topic echo /${ROS_NAME}/scan
ros2 topic echo /${ROS_NAME}/camera/image_raw
ros2 topic echo /${ROS_NAME}/imu/data

# Monitor system performance
htop
df -h
```

## Emergency Procedures

### Emergency Stop
1. Press physical emergency stop button
2. Turn off main power switch
3. Assess the situation
4. Document any issues

### System Recovery
1. Check for damage
2. Verify connections
3. Restart system
4. Test functionality

## Getting Help

If you need additional assistance:

1. Check the troubleshooting guides
2. Review system logs
3. Contact the PARTS team
4. Document issues for future reference

---

*For setup procedures, see [Setup](../setup/index.md)*
*For daily operations, see [Key Operations](index.md)*

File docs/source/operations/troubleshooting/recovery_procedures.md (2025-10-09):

# Recovery Procedures

This guide provides step-by-step recovery procedures for various system failures in the RCR Common Robotics Platform.

## Emergency Recovery

### Immediate Actions

1. **Emergency Stop**
   - Press physical emergency stop button
   - Turn off main power switch
   - Assess the situation safely

2. **Safety Check**
   - Ensure robot is in safe location
   - Check for any damage
   - Verify no immediate hazards

3. **Documentation**
   - Note what happened
   - Record error messages
   - Document system state

## System Recovery Procedures

### 1. Complete System Restart

**Procedure:**
1. Power off robot completely
2. Wait 10 seconds
3. Power on robot
4. Launch system
5. Verify all components

**Commands:**
```bash
# Power off
sudo shutdown -h now

# Power on and launch
ros2 launch common_platform launch_robot.launch.py
```

### 2. Software Recovery

**Restart ROS2 Nodes:**
```bash
# Kill all ROS2 nodes
ros2 daemon stop
ros2 daemon start

# Restart launch file
ros2 launch common_platform launch_robot.launch.py
```

**Reset Configuration:**
```bash
# Reset to default configuration
cp config/default/* config/

# Restart system
ros2 launch common_platform launch_robot.launch.py
```

### 3. Hardware Recovery

**Check Connections:**
1. Power off robot
2. Check all cable connections
3. Verify power connections
4. Test sensor connections
5. Power on and test

**Reset Hardware:**
```bash
# Reset USB devices
sudo modprobe -r usb_storage
sudo modprobe usb_storage

# Reset I2C bus
sudo modprobe -r i2c_dev
sudo modprobe i2c_dev
```

## Component-Specific Recovery

### Power System Recovery

**Battery Issues:**
1. Check battery voltage
2. Verify charging system
3. Test under load
4. Replace if necessary

**Power Supply Issues:**
1. Check power connections
2. Verify voltage levels
3. Test power distribution
4. Replace faulty components

### Motor System Recovery

**Motor Driver Recovery:**
1. Check driver connections
2. Verify power supply
3. Test driver functionality
4. Replace if necessary

**Encoder Recovery:**
1. Check encoder wiring
2. Verify encoder counts
3. Test encoder resolution
4. Replace if necessary

### Sensor Recovery

**LiDAR Recovery:**
1. Check USB connection
2. Verify power supply
3. Test serial communication
4. Restart LiDAR node

**Camera Recovery:**
1. Check USB connection
2. Verify power supply
3. Test video device
4. Restart camera node

**IMU Recovery:**
1. Check I2C connection
2. Verify power supply
3. Test I2C communication
4. Restart IMU node

## Navigation Recovery

### Localization Recovery

**Lost Localization:**
1. Stop robot movement
2. Set initial pose in RViz
3. Verify sensor data
4. Restart localization

**Poor Localization:**
1. Check sensor data quality
2. Verify map quality
3. Tune AMCL parameters
4. Restart localization

### Path Planning Recovery

**No Path Found:**
1. Check goal accessibility
2. Verify costmap
3. Adjust parameters
4. Restart planner

**Path Planning Failed:**
1. Check costmap data
2. Verify sensor data
3. Restart planner
4. Check for errors

## Data Recovery

### Log Recovery

**System Logs:**
```bash
# Check system logs
journalctl -u ros2
journalctl -u robot

# Save important logs
journalctl -u ros2 > /tmp/ros2_recovery.log
```

**ROS2 Logs:**
```bash
# Check ROS2 logs
ros2 log list
ros2 log show

# Save ROS2 logs
ros2 log save /tmp/ros2_logs
```

### Configuration Recovery

**Backup Configuration:**
```bash
# Backup current configuration
cp -r config/ config_backup_$(date +%Y%m%d_%H%M%S)/

# Restore from backup
cp -r config_backup_YYYYMMDD_HHMMSS/* config/
```

**Reset to Defaults:**
```bash
# Reset configuration
git checkout config/
```

## Network Recovery

### Communication Recovery

**USB Recovery:**
```bash
# Reset USB subsystem
sudo modprobe -r usb_storage
sudo modprobe usb_storage

# Check USB devices
lsusb
```

**Serial Recovery:**
```bash
# Check serial devices
ls /dev/tty*

# Reset serial ports
sudo chmod 666 /dev/ttyUSB0
```

**Network Recovery:**
```bash
# Restart network
sudo systemctl restart networking

# Check network status
ip addr show
```

## Performance Recovery

### System Performance

**Resource Recovery:**
```bash
# Check system resources
htop
df -h
free -h

# Clean up if needed
sudo apt autoremove
sudo apt autoclean
```

**Process Recovery:**
```bash
# Kill problematic processes
sudo pkill -f ros2
sudo pkill -f robot

# Restart system
ros2 launch common_platform launch_robot.launch.py
```

### Memory Recovery

**Memory Issues:**
```bash
# Check memory usage
free -h

# Clear memory cache
sudo sync
sudo echo 3 > /proc/sys/vm/drop_caches
```

## Recovery Verification

### System Verification

**Component Check:**
```bash
# Check all nodes
ros2 node list

# Check all topics
ros2 topic list

# Check all services
ros2 service list
```

**Functionality Test:**
```bash
# Test sensors
ros2 topic echo /${ROS_NAME}/scan
ros2 topic echo /${ROS_NAME}/camera/image_raw
ros2 topic echo /${ROS_NAME}/imu/data

# Test motors
ros2 topic pub /cmd_vel geometry_msgs/msg/Twist "{}"
```

### Performance Verification

**System Performance:**
```bash
# Check system load
uptime
htop

# Check disk usage
df -h

# Check network
ping google.com
```

## Prevention

### Regular Maintenance

**Daily Checks:**
- Visual inspection
- Check connections
- Verify data quality

**Weekly Checks:**
- System performance
- Log analysis
- Configuration backup

**Monthly Checks:**
- Full system test
- Component inspection
- Performance review

### Monitoring

**System Monitoring:**
- Monitor system resources
- Check for errors
- Track performance

**Health Checks:**
- Implement health checks
- Monitor sensor data
- Track system status

## Recovery Documentation

### Recovery Log

**Document Recovery:**
- Date and time
- What failed
- Recovery steps taken
- Results
- Lessons learned

**Update Procedures:**
- Update recovery procedures
- Document new issues
- Improve recovery process

---

*For common issues, see [Common Issues](common_issues.md)*
*For error codes, see [Error Codes](error_codes.md)*
*For troubleshooting, see [Troubleshooting](../troubleshooting/index.md)*

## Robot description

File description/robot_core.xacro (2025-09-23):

<?xml version="1.0"?>
<robot xmlns:xacro="http://www.ros.org/wiki/xacro">

    <xacro:include filename="inertial_macros.xacro"/>


    <xacro:property name="chassis_diameter" value="0.245"/>
    <xacro:property name="chassis_height" value="0.1013"/>
    <xacro:property name="chassis_mass" value="1.0"/>
    <xacro:property name="wheel_radius" value="0.035"/>
    <xacro:property name="wheel_thickness" value="0.008"/>
    <xacro:property name="wheel_mass" value="0.05"/>
    <xacro:property name="wheel_offset_x" value="0.000"/>
    <xacro:property name="wheel_offset_y" value="0.07039"/>
    <xacro:property name="wheel_offset_z" value="0.010"/>
    <xacro:property name="caster_wheel_radius" value="0.013"/>
    <xacro:property name="caster_wheel_mass" value="0.01"/>
    <xacro:property name="caster_wheel_offset_x" value="0.044174"/>
    <xacro:property name="caster_wheel_offset_z" value="${wheel_offset_z - wheel_radius + caster_wheel_radius}"/>

    <material name="white">
        <color rgba="1 1 1 1" />
    </material>

    <material name="orange">
        <color rgba="1 0.3 0.1 1"/>
    </material>

    <material name="blue">
        <color rgba="0.2 0.2 1 1"/>
    </material>

    <material name="black">
        <color rgba="0 0 0 1"/>
    </material>

    <material name="red">
        <color rgba="1 0 0 1"/>
    </material>

    <!-- BASE LINK -->

    <link name="base_link">

    </link>

    <!-- BASE_FOOTPRINT LINK -->

    <joint name="base_footprint_joint" type="fixed">
        <parent link="base_link"/>
        <child link="base_footprint"/>
        <origin xyz="0 0 ${-wheel_radius}" rpy="0 0 0"/>
    </joint>

    <link name="base_footprint">
    </link>


    <!-- CHASSIS LINK -->

    <joint name="chassis_joint" type="fixed">
        <parent link="base_link"/>
        <child link="chassis"/>
        <origin xyz="${-wheel_offset_x} 0 ${-wheel_offset_z}"/>
    </joint>

    <link name="chassis">
        <visual>
            <origin xyz="0 0 0" rpy="0 0 0"/>
            <geometry>
                <mesh filename="package://common_platform/meshes/chassis.stl" scale=".001 .001 .001"/>
            </geometry>
            <material name="orange"/>
        </visual>
        <collision>
            <origin xyz="${chassis_diameter/2} 0 ${wheel_offset_z - wheel_radius + chassis_height/2}"/>
            <geometry>
                <cylinder radius="${chassis_diameter/2}" length="${chassis_height}"/>
            </geometry>
        </collision>
        <xacro:inertial_cylinder mass="0.5" length="${chassis_height}" radius="${chassis_diameter/2}">
            <origin xyz="0 0 ${wheel_offset_z - wheel_radius + chassis_height/2}" rpy="0 0 0"/>
        </xacro:inertial_cylinder>
    </link>

    <gazebo reference="chassis">
        <material>Gazebo/Orange</material>
    </gazebo>

    <!-- LEFT WHEEL LINK -->

    <joint name="left_wheel_joint" type="continuous">
        <parent link="base_link"/>
        <child link="left_wheel"/>
        <origin xyz="0 ${wheel_offset_y} 0" rpy="-${pi/2} 0 0" />
        <axis xyz="0 0 1"/>
    </joint>

    <link name="left_wheel">
        <visual>
            <geometry>
                <cylinder radius="${wheel_radius}" length="${wheel_thickness}"/>
            </geometry>
            <material name="blue"/>
        </visual>
        <collision>
            <geometry>
                <sphere radius="${wheel_radius}"/>
            </geometry>
        </collision>
        <xacro:inertial_cylinder mass="${wheel_mass}" length="${wheel_thickness}" radius="${wheel_radius}">
            <origin xyz="0 0 0" rpy="0 0 0"/>
        </xacro:inertial_cylinder>
    </link>

    <gazebo reference="left_wheel">
        <material>Gazebo/Blue</material>
    </gazebo>




    <!-- RIGHT WHEEL LINK -->

    <joint name="right_wheel_joint" type="continuous">
        <parent link="base_link"/>
        <child link="right_wheel"/>
        <origin xyz="0 ${-wheel_offset_y} 0" rpy="${pi/2} 0 0" />
        <axis xyz="0 0 -1"/>
    </joint>

    <link name="right_wheel">
        <visual>
            <geometry>
                <cylinder radius="${wheel_radius}" length="${wheel_thickness}"/>
            </geometry>
            <material name="blue"/>
        </visual>
        <collision>
            <geometry>
                <sphere radius="${wheel_radius}"/>
            </geometry>
        </collision>
        <xacro:inertial_cylinder mass="${wheel_mass}" length="${wheel_thickness}" radius="${wheel_radius}">
            <origin xyz="0 0 0" rpy="0 0 0"/>
        </xacro:inertial_cylinder>
    </link>

    <gazebo reference="right_wheel">
        <material>Gazebo/Blue</material>
    </gazebo>


    <!-- CASTER WHEEL LINK -->

    <joint name="caster_wheel_joint" type="fixed">
        <parent link="chassis"/>
        <child link="caster_wheel"/>
        <origin xyz="${caster_wheel_offset_x} 0 ${caster_wheel_offset_z}"/>
    </joint>


    <link name="caster_wheel">
        <visual>
            <geometry>
                <sphere radius="${caster_wheel_radius}"/>
            </geometry>
            <material name="white"/>
        </visual>
        <collision>
            <geometry>
                <sphere radius="${caster_wheel_radius}"/>
            </geometry>
        </collision>
        <xacro:inertial_sphere mass="${caster_wheel_mass}" radius="${caster_wheel_radius}">
            <origin xyz="0 0 0" rpy="0 0 0"/>
        </xacro:inertial_sphere>
    </link>

    <gazebo reference="caster_wheel">
        <material>Gazebo/White</material>
        <mu1 value="0.001"/>
        <mu2 value="0.001"/>
    </gazebo>

</robot>

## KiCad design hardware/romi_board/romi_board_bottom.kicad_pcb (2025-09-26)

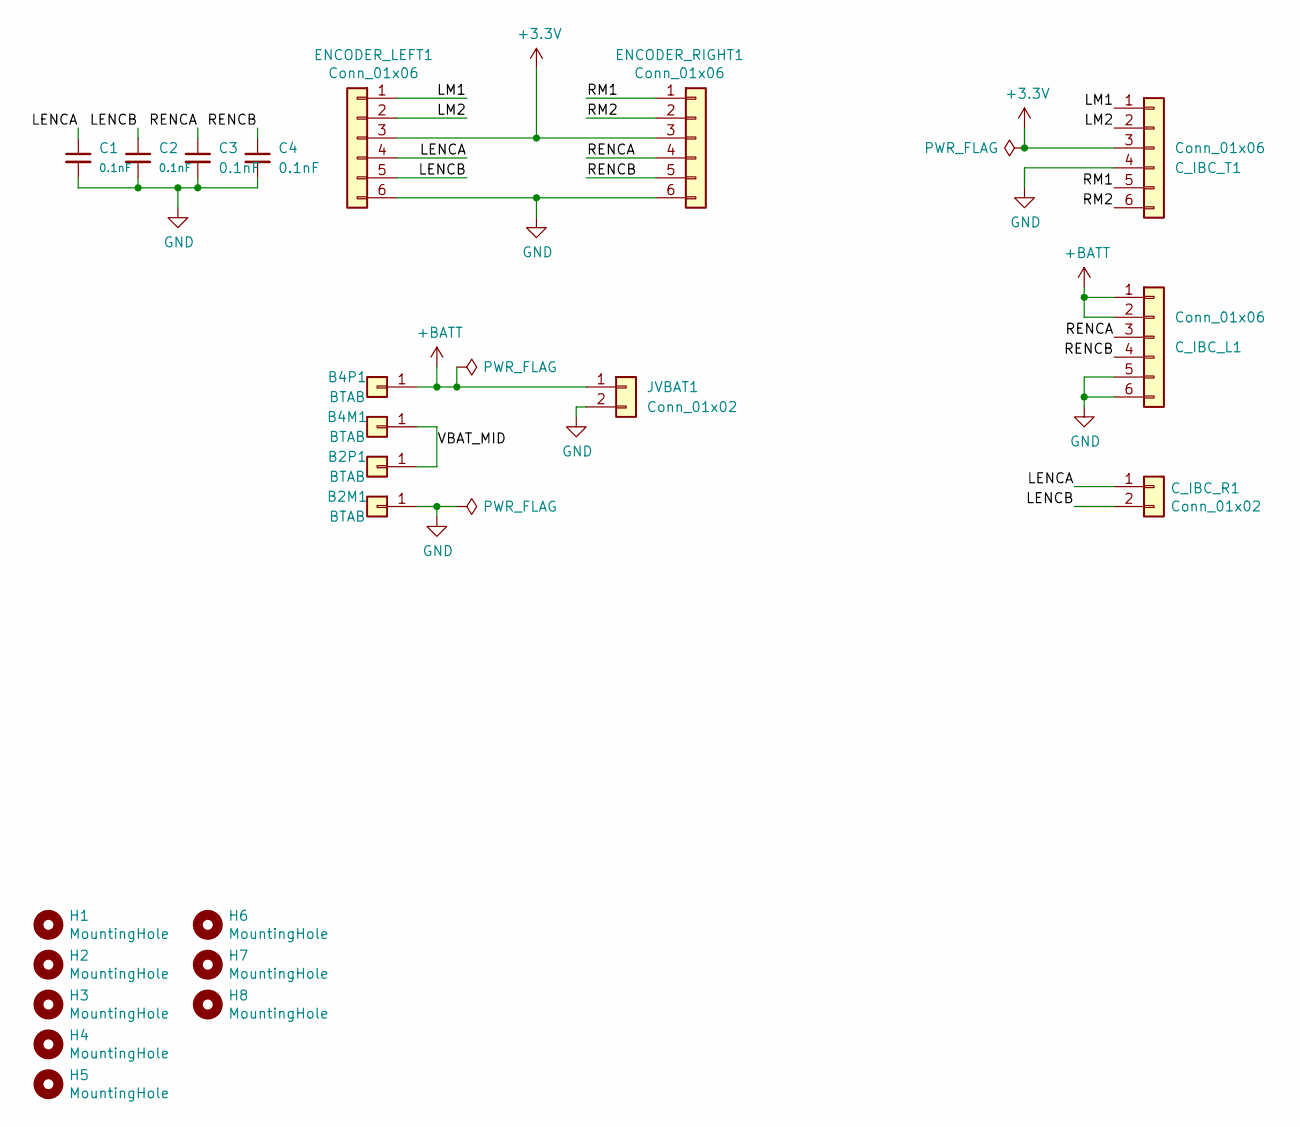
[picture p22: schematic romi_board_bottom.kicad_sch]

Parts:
B2M1, B2P1, B4M1, B4P1: BTAB; romi_battery_tab
C1, C2, C3, C4: 0.1nF; C_0805_2012Metric_Pad1.18x1.45mm_HandSolder
C_IBC_L1: Conn_01x06; PinHeader_1x06_P2.54mm_Vertical
C_IBC_R1: Conn_01x02; PinHeader_1x02_P2.54mm_Vertical
C_IBC_T1: Conn_01x06; PinHeader_1x06_P2.54mm_Vertical
ENCODER_LEFT1: Conn_01x06; PinHeader_1x06_P2.54mm_Vertical
ENCODER_RIGHT1: Conn_01x06; PinHeader_1x06_P2.54mm_Vertical
H1, H2, H3, H4, H5, H6: MountingHole; MountingHole_2.5mm
H7, H8: MountingHole; MountingHole_6mm
JVBAT1: Conn_01x02; PinHeader_1x02_P2.54mm_Vertical

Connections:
+3.3V: C_IBC_T1.3, ENCODER_LEFT1.3, ENCODER_RIGHT1.3
+BATT: B4P1.1, C_IBC_L1.1, C_IBC_L1.2, JVBAT1.1
/LENCA: C1.1, C_IBC_R1.1, ENCODER_LEFT1.4
/LENCB: C2.1, C_IBC_R1.2, ENCODER_LEFT1.5
/LM1: C_IBC_T1.1, ENCODER_LEFT1.1
/LM2: C_IBC_T1.2, ENCODER_LEFT1.2
/RENCA: C3.1, C_IBC_L1.3, ENCODER_RIGHT1.4
/RENCB: C4.1, C_IBC_L1.4, ENCODER_RIGHT1.5
/RM1: C_IBC_T1.5, ENCODER_RIGHT1.1
/RM2: C_IBC_T1.6, ENCODER_RIGHT1.2
/VBAT_MID: B2P1.1, B4M1.1
GND: B2M1.1, C1.2, C2.2, C3.2, C4.2, C_IBC_L1.5, C_IBC_L1.6, C_IBC_T1.4, ENCODER_LEFT1.6, ENCODER_RIGHT1.6, JVBAT1.2

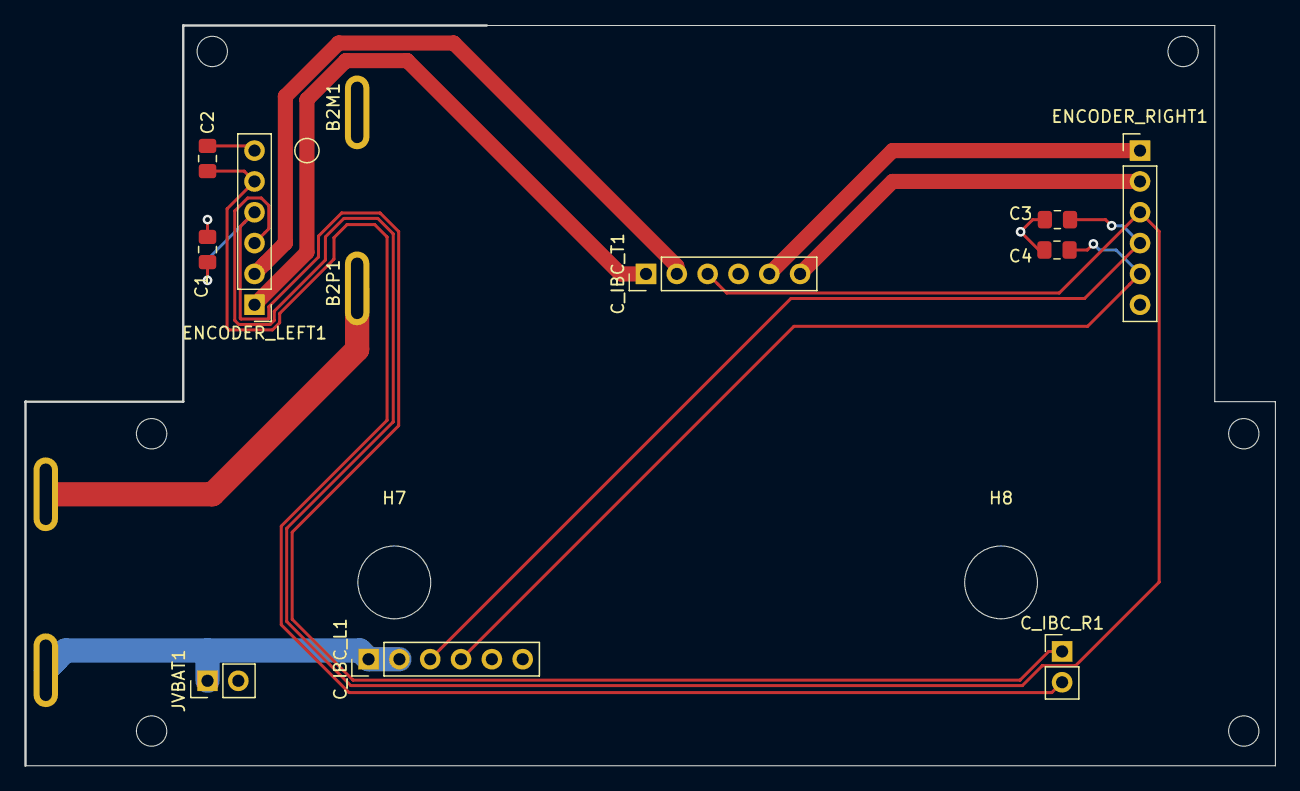
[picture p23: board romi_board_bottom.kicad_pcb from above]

Board: 2 copper layers, 103.0 x 61.0 mm, 22 parts (0 on the bottom side), 12 nets.

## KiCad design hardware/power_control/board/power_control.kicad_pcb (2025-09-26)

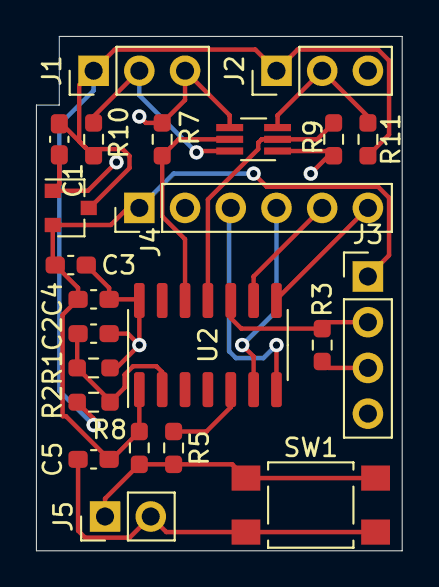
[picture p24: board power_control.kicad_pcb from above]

Board: 2 copper layers, 20.3 x 28.6 mm, 23 parts (0 on the bottom side), 16 nets.

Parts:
C1, C2, C3, C4, C5: C; C_0603_1608Metric_Pad1.08x0.95mm_HandSolder
J1, J2: Conn_01x03; PinHeader_1x03_P2.54mm_Vertical
J3: Conn_01x04; PinHeader_1x04_P2.54mm_Vertical
J4: Conn_01x06; PinHeader_1x06_P2.54mm_Vertical
J5: Conn_01x02; PinHeader_1x02_P2.54mm_Vertical
J6: Conn_01x06; SOT-363_SC-70-6_Handsoldering
R1, R2, R3, R5, R7, R8, R9, R10, R11: R_Small_US; R_0603_1608Metric_Pad0.98x0.95mm_HandSolder
SW1: SW_Push; SW_SPST_TL3305A
U1: MCP1703A-5002_SOT23; SOT-23
U2: ATtiny1604-SS; SOIC-14_3.9x8.7mm_P1.27mm

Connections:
+3V3: C3.1, C4.1, C5.1, J3.1, J4.1, R8.2, U1.2, U2.1
+BATT: C1.1, J1.1, J2.1, R2.1, R10.1, R11.1, U1.3
/PBTN: J5.1, R5.2, R8.1, SW1.1
/PMTR_CTRL: J6.5, R7.1, U2.12
/PSM: J2.2, J6.3, R11.2
/PSS: J1.2, J6.6, R10.2
/PSYS_CTRL: J6.2, R9.1, U2.11
/PWR_BUTTON: R5.1, U2.5
/RX: J4.4, U2.6
/SCL: J4.5, U2.9
/SDA: J4.6, U2.8
/TX: J4.3, U2.7
/UPDI: J3.2, R3.2, U2.10
/UPDI_TX: J3.3, R3.1
/VBAT_DIV: C2.1, R1.1, R2.2, U2.2
GND: C1.2, C2.2, C3.2, C4.2, C5.2, J1.3, J2.3, J3.4, J4.2, J5.2, J6.1, J6.4, R1.2, R7.2, R9.2, SW1.2, U1.1, U2.14

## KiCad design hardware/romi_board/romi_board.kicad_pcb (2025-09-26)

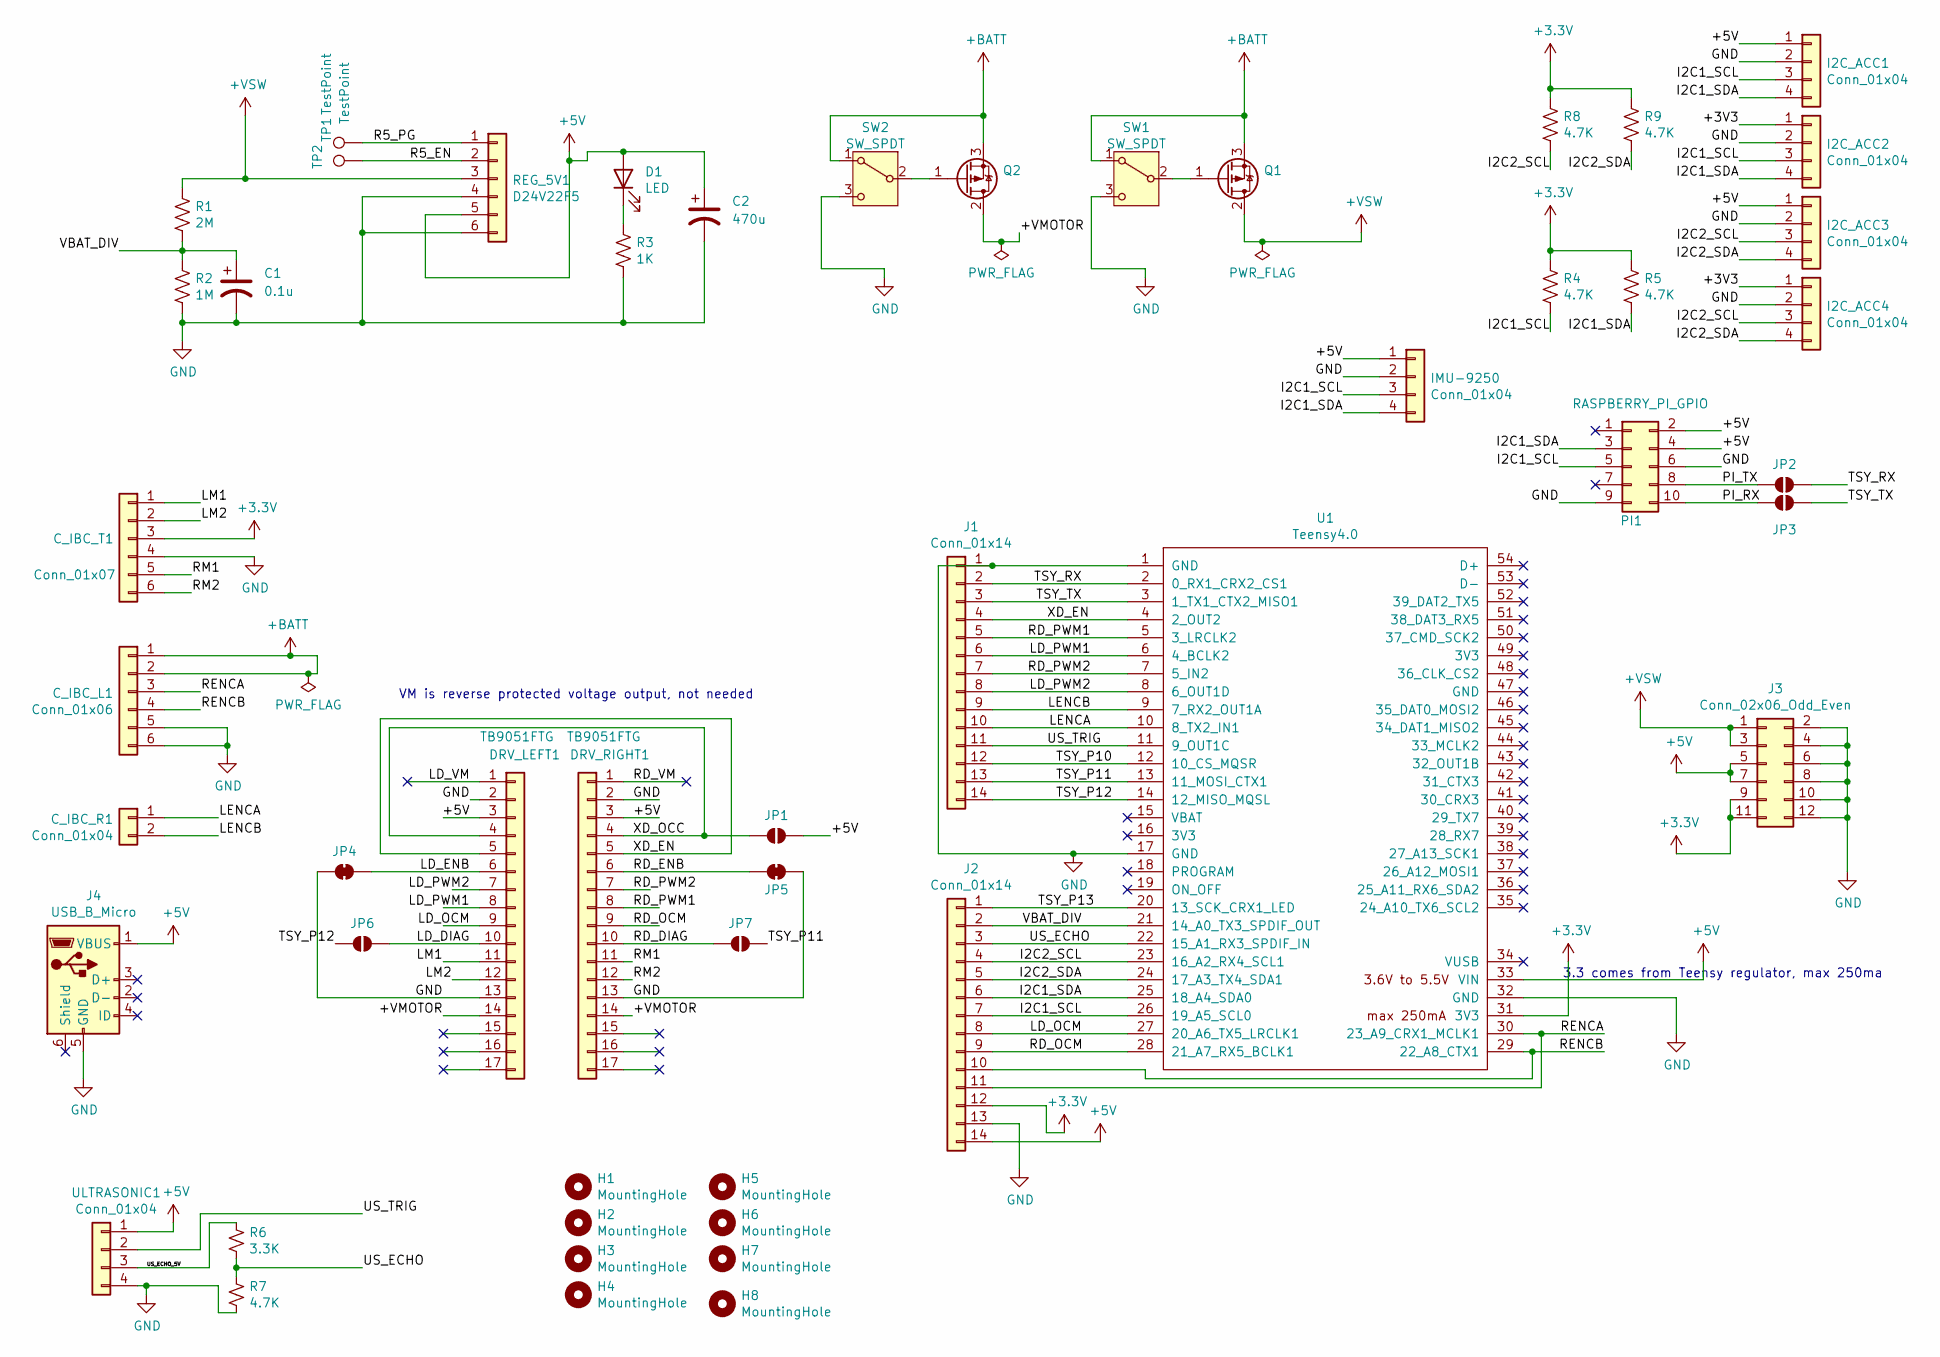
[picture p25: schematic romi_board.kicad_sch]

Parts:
C1: 0.1u; C_Disc_D5.0mm_W2.5mm_P5.00mm
C2: 470u; CP_Radial_D6.3mm_P2.50mm
C_IBC_L1: Conn_01x06; PinHeader_1x06_P2.54mm_Vertical
C_IBC_R1: Conn_01x04; PinHeader_1x02_P2.54mm_Vertical
C_IBC_T1: Conn_01x07; PinHeader_1x06_P2.54mm_Vertical
D1: LED; LED_D5.0mm
DRV_LEFT1: TB9051FTG; TB9051FTG_db
DRV_RIGHT1: TB9051FTG; TB9051FTG_db
H1, H2, H3, H4: MountingHole; MountingHole_2.5mm
H5, H6, H7, H8: MountingHole; MountingHole_6mm_passthrough
I2C_ACC1, I2C_ACC2, I2C_ACC3, I2C_ACC4: Conn_01x04; PinHeader_1x04_P2.54mm_Vertical
IMU-9250: Conn_01x04; MPU9250_BB
J1, J2: Conn_01x14; PinHeader_1x14_P2.54mm_Vertical
J3: Conn_02x06_Odd_Even; PinHeader_2x06_P2.54mm_Vertical
J4: USB_B_Micro; USB_Micro-B_Molex_47346-0001
JP1, JP2, JP3, JP6, JP7: SolderJumper_2_Open; SolderJumper-2_P1.3mm_Open_RoundedPad1.0x1.5mm
JP4, JP5: SolderJumper_2_Bridged; SolderJumper-2_P1.3mm_Bridged_RoundedPad1.0x1.5mm
PI1: RASPBERRY_PI_GPIO; PinHeader_2x05_P2.54mm_Vertical
Q1, Q2: Q_PMOS_DGS; TO-251-3_Vertical
R1: 2M; R_Axial_DIN0309_L9.0mm_D3.2mm_P2.54mm_Vertical
R2: 1M; R_Axial_DIN0309_L9.0mm_D3.2mm_P2.54mm_Vertical
R3: 1K; R_Axial_DIN0309_L9.0mm_D3.2mm_P2.54mm_Vertical
R4, R5, R7, R8, R9: 4.7K; R_Axial_DIN0309_L9.0mm_D3.2mm_P2.54mm_Vertical
R6: 3.3K; R_Axial_DIN0309_L9.0mm_D3.2mm_P2.54mm_Vertical
REG_5V1: D24V22F5; D24V2F5_bb
SW1, SW2: SW_SPDT; Switch
TP1, TP2: TestPoint; TestPoint_Pad_D2.0mm
U1: Teensy4.0; Teensy40_simple
ULTRASONIC1: Conn_01x04; PinHeader_1x04_P2.54mm_Vertical

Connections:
+5V: C2.1, D1.2 (A), DRV_LEFT1.3, DRV_RIGHT1.3, I2C_ACC1.1, I2C_ACC3.1, IMU-9250.1, J2.14, J3.5, J3.7, J4.1 (VBUS), JP1.1 (A), PI1.2, PI1.4, REG_5V1.5, U1.33 (VIN), ULTRASONIC1.1
+BATT: C_IBC_L1.1, C_IBC_L1.2, Q1.3 (S), Q2.3 (S), SW1.1 (A), SW2.1 (A)
+VSW: J3.1, J3.3, Q1.2 (D), R1.1, REG_5V1.3
/+VMOTOR: DRV_LEFT1.14, DRV_RIGHT1.14, Q2.2 (D)
/I2C1_SCL: I2C_ACC1.3, I2C_ACC2.3, IMU-9250.3, J2.7, PI1.5, R4.2, U1.26 (19_A5_SCL0)
/I2C1_SDA: I2C_ACC1.4, I2C_ACC2.4, IMU-9250.4, J2.6, PI1.3, R5.2, U1.25 (18_A4_SDA0)
/I2C2_SCL: I2C_ACC3.3, I2C_ACC4.3, J2.4, R8.2, U1.23 (16_A2_RX4_SCL1)
/I2C2_SDA: I2C_ACC3.4, I2C_ACC4.4, J2.5, R9.2, U1.24 (17_A3_TX4_SDA1)
/LD_DIAG: DRV_LEFT1.10, JP6.1 (A)
/LD_ENB: DRV_LEFT1.6, JP4.2 (B)
/LD_OCM: DRV_LEFT1.9, J2.8, U1.27 (20_A6_TX5_LRCLK1)
/LD_PWM1: DRV_LEFT1.8, J1.6, U1.6 (4_BCLK2)
/LD_PWM2: DRV_LEFT1.7, J1.8, U1.8 (6_OUT1D)
/LD_VM: DRV_LEFT1.1
/LENCA: C_IBC_R1.1, J1.10, U1.10 (8_TX2_IN1)
/LENCB: C_IBC_R1.2, J1.9, U1.9 (7_RX2_OUT1A)
/LM1: C_IBC_T1.1, DRV_LEFT1.11
/LM2: C_IBC_T1.2, DRV_LEFT1.12
/PI_RX: JP3.1 (A), PI1.10
/PI_TX: JP2.1 (A), PI1.8
/R5_EN: REG_5V1.2, TP2.1
/R5_PG: REG_5V1.1, TP1.1
/RD_DIAG: DRV_RIGHT1.10, JP7.2 (B)
/RD_ENB: DRV_RIGHT1.6, JP5.2 (B)
/RD_OCM: DRV_RIGHT1.9, J2.9, U1.28 (21_A7_RX5_BCLK1)
/RD_PWM1: DRV_RIGHT1.8, J1.5, U1.5 (3_LRCLK2)
/RD_PWM2: DRV_RIGHT1.7, J1.7, U1.7 (5_IN2)
/RD_VM: DRV_RIGHT1.1
/RENCA: C_IBC_L1.3, J2.11, U1.30 (23_A9_CRX1_MCLK1)
/RENCB: C_IBC_L1.4, J2.10, U1.29 (22_A8_CTX1)
/RM1: C_IBC_T1.5, DRV_RIGHT1.11
/RM2: C_IBC_T1.6, DRV_RIGHT1.12
/TSY_P10: J1.12, U1.12 (10_CS_MQSR)
/TSY_P11: J1.13, JP7.1 (A), U1.13 (11_MOSI_CTX1)
/TSY_P12: J1.14, JP6.2 (B), U1.14 (12_MISO_MQSL)
/TSY_P13: J2.1, U1.20 (13_SCK_CRX1_LED)
/TSY_RX: J1.2, JP2.2 (B), U1.2 (0_RX1_CRX2_CS1)
/TSY_TX: J1.3, JP3.2 (B), U1.3 (1_TX1_CTX2_MISO1)
/US_ECHO: J2.3, R6.2, R7.1, U1.22 (15_A1_RX3_SPDIF_IN)
/US_ECHO_5V: R6.1, ULTRASONIC1.3
/US_TRIG: J1.11, U1.11 (9_OUT1C), ULTRASONIC1.2
/VBAT_DIV: C1.1, J2.2, R1.2, R2.1, U1.21 (14_A0_TX3_SPDIF_OUT)
/XD_EN: DRV_LEFT1.5, DRV_RIGHT1.5, J1.4, U1.4 (2_OUT2)
/XD_OCC: DRV_LEFT1.4, DRV_RIGHT1.4, JP1.2 (B)
GND: C1.2, C2.2, C_IBC_L1.5, C_IBC_L1.6, C_IBC_T1.4, DRV_LEFT1.2, DRV_LEFT1.13, DRV_RIGHT1.2, DRV_RIGHT1.13, I2C_ACC1.2, I2C_ACC2.2, I2C_ACC3.2, I2C_ACC4.2, IMU-9250.2, J1.1, J2.13, J3.2, J3.4, J3.6, J3.8, J3.10, J3.12, J4.5 (GND), JP4.1 (A), JP5.1 (A), PI1.6, PI1.9, R2.2, R3.2, R7.2, REG_5V1.4, REG_5V1.6, SW1.3 (C), SW2.3 (C), U1.1 (GND), U1.17 (GND), U1.32 (GND), ULTRASONIC1.4
unnamed: D1.1 (K), R3.1
unnamed: Q1.1 (G), SW1.2 (B)
unnamed: Q2.1 (G), SW2.2 (B)

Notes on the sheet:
3.3 comes from Teensy regulator, max 250ma
VM is reverse protected voltage output, not needed

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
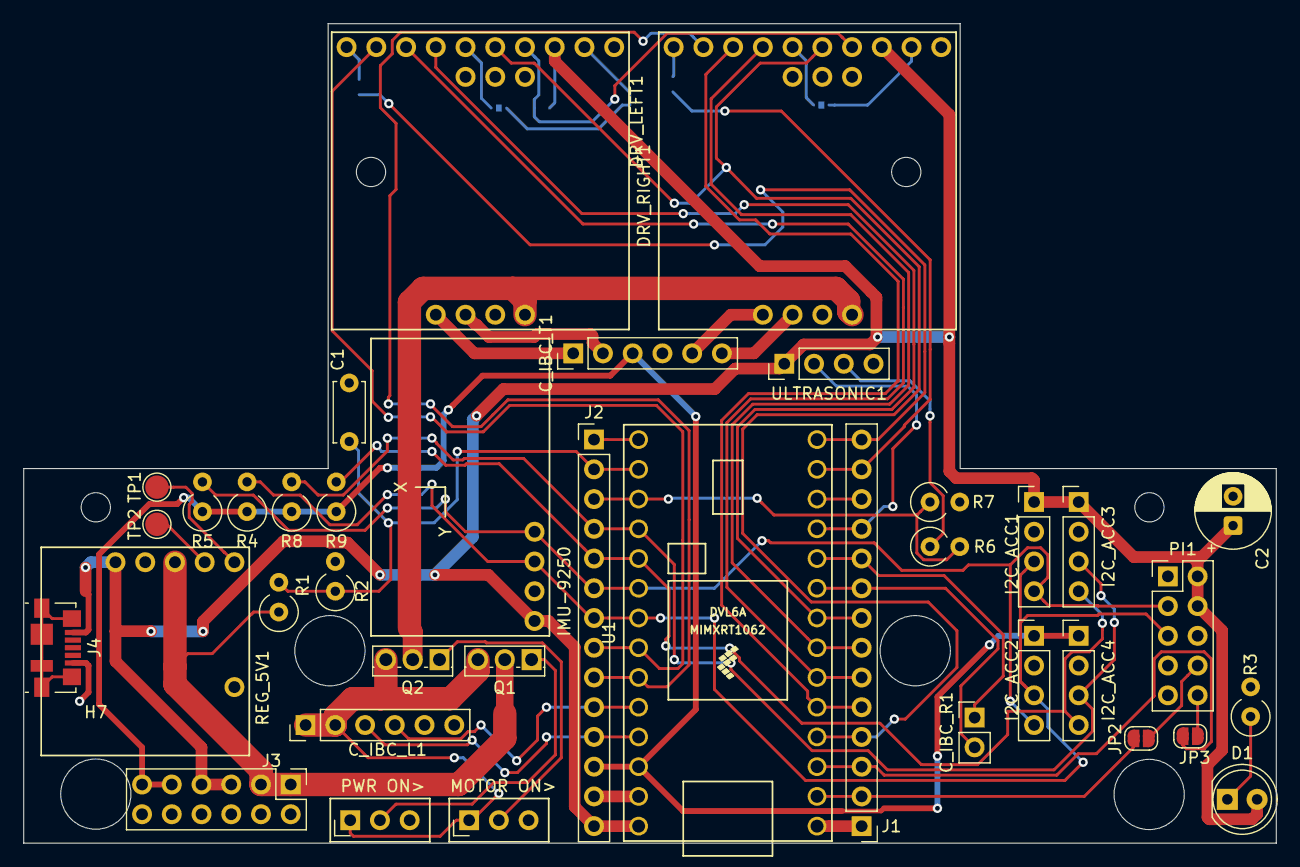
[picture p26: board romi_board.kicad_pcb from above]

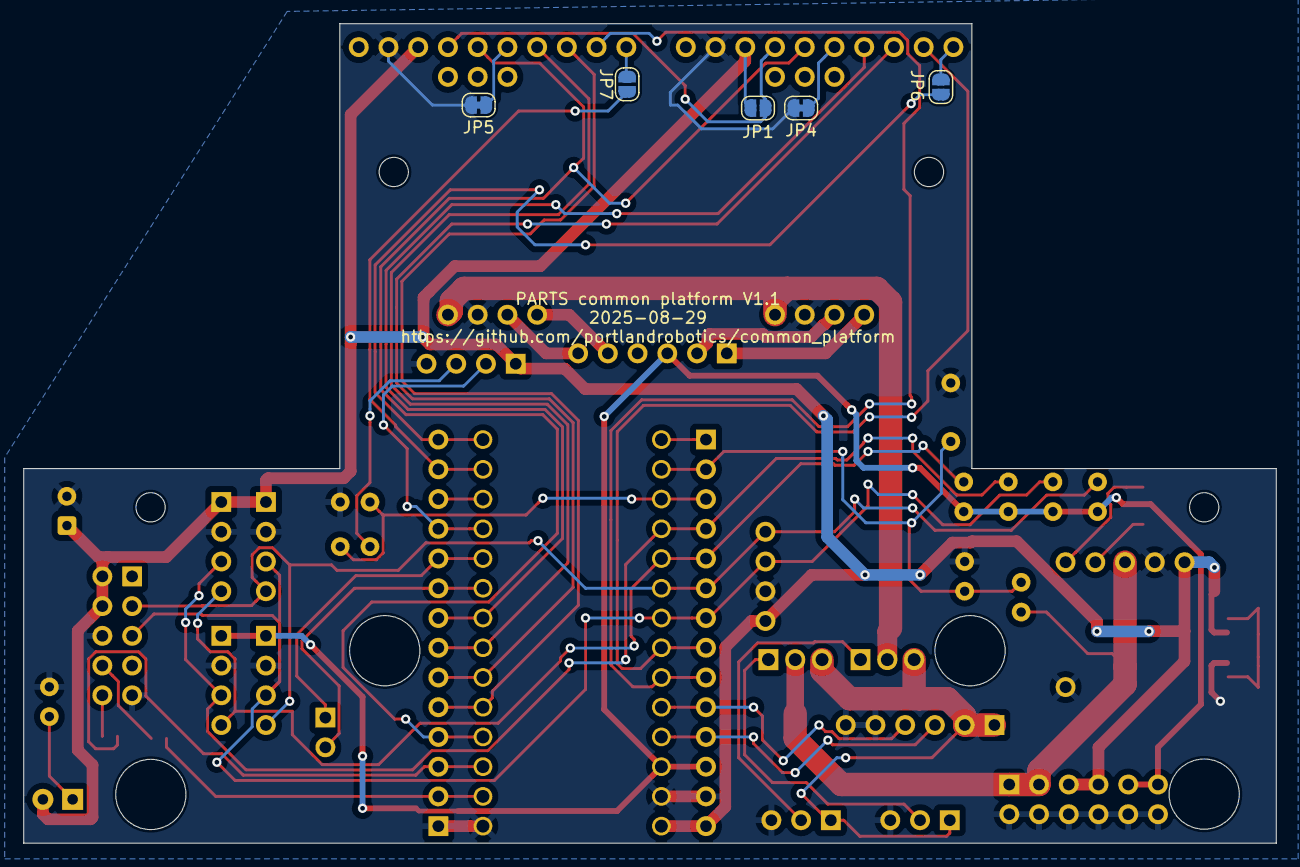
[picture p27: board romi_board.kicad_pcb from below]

Board: 2 copper layers, 107.0 x 70.0 mm, 51 parts (5 on the bottom side), 47 nets.

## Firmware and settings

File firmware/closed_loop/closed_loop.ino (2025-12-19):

/**
 * @file closed_loop.ino
 * @brief Firmware for a closed-loop motor control system with optional ROS integration.
 *
 * This firmware is designed to control a robot with two motors, using PID controllers
 * for precise speed and position control. It supports two modes of operation:
 * - **Standalone Mode**: The robot operates independently, using serial commands for control.
 * - **ROS Mode**: The robot integrates with the Robot Operating System (ROS) for remote control
 *   and communication via the micro-ROS framework.
 *
 * ## Features:
 * - **Motor Control**: PID-based speed control for left and right motors.
 * - **Odometry**: Tracks the robot's position and orientation using encoder feedback.
 * - **Command Parsing**: Supports serial commands for motor control, PID tuning, and state reset.
 * - **ROS Integration**: Subscribes to `cmd_vel` messages for velocity commands and manages
 *   connection to a ROS agent.
 * - **Safety Features**: Includes overcurrent protection and motor disable functionality.
 * - **Status Reporting**: Periodically outputs robot status, including odometry and motor speeds.
 *
 * ## Code Structure:
 * - **Global Configuration**: Pin definitions, ROS mode selection, and debug settings.
 * - **Classes**:
 *   - `PidControl`: Implements a PID controller for motor speed control.
 *   - `MotorControl`: Manages motor speed, encoder feedback, and PWM output.
 *   - `Point` and `Motion`: Handle robot position and orientation tracking.
 * - **Global Objects**: Instances of `MotorControl`, `Motion`, and `RobotState` for managing
 *   the robot's state and behavior.
 * - **ROS-Specific Logic**: Handles ROS communication, including agent connection and message
 *   subscription.
 * - **Main Functions**:
 *   - `setup()`: Initializes hardware, ROS (if enabled), and robot state.
 *   - `loop()`: Main control loop, handling sensor updates, motor control, ROS communication,
 *     and serial command processing.
 *   - `drivecontrol()`: Calculates motor target speeds based on ROS or standalone commands.
 *   - `parseCommand()`: Processes serial commands for robot control and configuration.
 *
 * ## Usage:
 * - Set `#define ROS` to `1` for ROS mode or `0` for standalone mode.
 * - In standalone mode, use serial commands to control the robot (e.g., `M` to toggle motors,
 *   `F` to move forward, `L`/`R` to turn).
 * - In ROS mode, ensure a ROS agent is running and publishing `cmd_vel` messages.
 *
 * ## Notes:
 * - Ensure proper tuning of PID parameters for optimal performance.
 * - Adjust hardware-specific constants (e.g., encoder counts per revolution, wheel diameter)
 *   as needed for your robot.
 */

// Pin Definitions
const int PIN_XD_EN = 2;
const int PIN_RD_PWM1 = 3;
const int PIN_LD_PWM1 = 4;
const int PIN_RD_PWM2 = 5;
const int PIN_LD_PWM2 = 6;
const int PIN_LENCB = 7;
const int PIN_LENCA = 8;
const int PIN_US_TRIG = 9;
const int PIN_VBAT = 14;
const int PIN_US_ECHO = 15;
const int PIN_LD_OCM = 20;
const int PIN_RD_OCM = 21;
const int PIN_RENCB = 22;
const int PIN_RENCA = 23;
const int LED_PIN = 13;

#include "setup.h"  // Include global configuration header
#include "PidControl.h"
#include "MotorControl.h"
#include "RobotState.h"
#include "Motion.h"
#include "TuningManager.h"

#include <Wire.h>
// #include <math.h>

// IMU address shared across modules (defined in RosInterface.cpp)
extern const uint8_t MPU9250_ADDR;

#if ROS
#include "RosInterface.h"
#endif  // ROS

// --- Global Objects ---
RobotState robotState;
MotorControl leftMotor(PIN_LD_OCM, PIN_LENCB, PIN_LENCA, PIN_LD_PWM2, PIN_LD_PWM1, "Left");
MotorControl rightMotor(PIN_RD_OCM, PIN_RENCA, PIN_RENCB, PIN_RD_PWM1, PIN_RD_PWM2, "Right");
Motion motion;

// Tuning manager for persistent motor parameters
TuningManager* tuningManager = nullptr;

// Encoder streaming state
bool encoderStreaming = false;

// I2C bus speed (reduce if IMU NACKs). Teensy supports setClock().
static const uint32_t I2C_CLOCK_HZ = 100000;  // 100 kHz for robustness

#if ROS
// ROS context instance
RosContext rosContext;
// Forward declaration for global ROS context (defined in RosInterface.cpp)
extern RosContext* global_ros_context;
// Forward declaration for reset function
void resetOdomWithMagnetometerCalibration(void *context);
#endif

void robotState_reset() {
  robotState.targetLinearVelocity = 0.0f;
  robotState.targetAngularVelocity = 0.0f;
  robotState.move = false;
  // cmdDrive = true; // Should reset keep motors enabled? Maybe not.
#if !ROS
  robotState.leftTargetDistance = 0;
  robotState.rightTargetDistance = 0;
  robotState.targetHeading = 0.0f;
  robotState.isMoving = false;
  robotState.corr = 0.0f;
#endif
  SERIAL_OUT.println("RobotState reset");
}


// --- Interrupt Service Routines for Encoders ---
// These ISRs directly manipulate the public volatile members of the global motor objects.

void leftEncoderInterrupt() {
  // Read current state of Left Motor's Encoder A and B pins
  // Note: digitalRead inside ISR is generally acceptable on fast MCUs like Teensy
  int8_t current_enc_val = (digitalRead(PIN_LENCA) ? 2 : 0) | (digitalRead(PIN_LENCB) ? 1 : 0);

  // Quadrature logic
  int8_t last_A_bit = (leftMotor.lastEnc >> 1) & 1;
  int8_t last_B_bit = leftMotor.lastEnc & 1;
  int8_t current_A_bit = (current_enc_val >> 1) & 1;
  int8_t current_B_bit = current_enc_val & 1;
  int8_t dir = (last_A_bit ^ current_B_bit) - (current_A_bit ^ last_B_bit);

  if (dir != 0) {
    // Physical forward rotation of the left motor causes its counter to decrease
    // (due to A leading B with the current XOR logic), so we invert dir here
    // to make the counter increase for forward motion.
    leftMotor.counter -= dir;          // Changed from += to -= to flip the direction for the left motor
    leftMotor.lastEncTime = micros();  // Update time of the edge
  }
  leftMotor.lastEnc = current_enc_val;  // Update last known state
}

void rightEncoderInterrupt() {
  // Read current state of Right Motor's Encoder A and B pins
  int8_t current_enc_val = (digitalRead(PIN_RENCA) ? 2 : 0) | (digitalRead(PIN_RENCB) ? 1 : 0);

  // Quadrature logic
  int8_t last_A_bit = (rightMotor.lastEnc >> 1) & 1;
  int8_t last_B_bit = rightMotor.lastEnc & 1;
  int8_t current_A_bit = (current_enc_val >> 1) & 1;
  int8_t current_B_bit = current_enc_val & 1;
  int8_t dir = (last_A_bit ^ current_B_bit) - (current_A_bit ^ last_B_bit);

  if (dir != 0) {
    rightMotor.counter += dir;
    rightMotor.lastEncTime = micros();
  }
  rightMotor.lastEnc = current_enc_val;
}


// --- ROS Specific Section ---
#if !ROS
// Differential PID only needed for non-ROS heading control during F commands
PidControl differential;
#endif

// --- IMU Diagnostic Function ---
/**
 * @brief Comprehensive IMU diagnostic to identify I2C communication issues
 * This function performs multiple tests to diagnose why the IMU isn't responding
 */
void diagnoseIMU() {
  const uint8_t AK8963_ADDR = 0x0C;
  const uint8_t WHO_AM_I_REG = 0x75;
  const uint8_t PWR_MGMT_1_REG = 0x6B;
  const uint8_t INT_PIN_CFG_REG = 0x37;
  
  SERIAL_OUT.println("=== IMU Diagnostic ===");
  SERIAL_OUT.println("Teensy 4.0 detected - using Wire (pins 18=SDA, 19=SCL)");
  // Ensure diagnostics use the same reduced I2C clock
  Wire.setClock(I2C_CLOCK_HZ);
  
  // Test 1: I2C Bus Scan - Check Wire (primary I2C bus)
  SERIAL_OUT.println("\n1. Scanning Wire bus (pins 18=SDA, 19=SCL) for devices...");
  int devicesFound = 0;
  for (uint8_t addr = 1; addr < 127; addr++) {
    Wire.beginTransmission(addr);
    uint8_t error = Wire.endTransmission();
    if (error == 0) {
      SERIAL_OUT.print("  Device found at address 0x");
      if (addr < 16) SERIAL_OUT.print("0");
      SERIAL_OUT.println(addr, HEX);
      devicesFound++;
    }
  }
  
  // Also check Wire1 bus (Teensy 4.0 has multiple I2C buses)
  #if defined(__IMXRT1062__)  // Teensy 4.0/4.1
  SERIAL_OUT.println("\n1b. Scanning Wire1 bus (pins 17=SDA, 16=SCL) for devices...");
  Wire1.begin();
    Wire1.setClock(I2C_CLOCK_HZ);
  int devicesFoundWire1 = 0;
  for (uint8_t addr = 1; addr < 127; addr++) {
    Wire1.beginTransmission(addr);
    uint8_t error = Wire1.endTransmission();
    if (error == 0) {
      SERIAL_OUT.print("  Device found on Wire1 at address 0x");
      if (addr < 16) SERIAL_OUT.print("0");
      SERIAL_OUT.println(addr, HEX);
      devicesFoundWire1++;
    }
  }
  if (devicesFoundWire1 > 0) {
    SERIAL_OUT.println("  WARNING: Devices found on Wire1, but code uses Wire!");
    SERIAL_OUT.println("  You may need to change code to use Wire1 instead of Wire");
  }
  devicesFound += devicesFoundWire1;
  #endif
  if (devicesFound == 0) {
    SERIAL_OUT.println("  ERROR: No I2C devices found! Check wiring and power.");
    
    // Check I2C pin states (for Teensy, default I2C pins are typically 18/19)
    // Note: We can't directly read which pins Wire library is using, but we can check common ones
    SERIAL_OUT.println("\n  I2C Pin State Check:");
    SERIAL_OUT.println("  (Note: Default I2C pins for Teensy 4.x are typically SDA=18, SCL=19)");
    SERIAL_OUT.println("  (For Teensy 3.x: SDA=18, SCL=19)");
    
    // Try to check if pins are floating (should be HIGH with pull-ups, LOW if shorted)
    // We'll check common I2C pins
    const int common_sda_pins[] = {18, 17, 16, 0};
    const int common_scl_pins[] = {19, 16, 17, 1};
    
    SERIAL_OUT.println("  Checking common SDA pins:");
    for (int i = 0; i < 4; i++) {
      pinMode(common_sda_pins[i], INPUT);
      delayMicroseconds(10);
      int state = digitalRead(common_sda_pins[i]);
      SERIAL_OUT.print("    Pin ");
      SERIAL_OUT.print(common_sda_pins[i]);
      SERIAL_OUT.print(": ");
      SERIAL_OUT.println(state == HIGH ? "HIGH (OK - pull-up present)" : "LOW (ERROR - shorted or no pull-up)");
    }
    
    SERIAL_OUT.println("  Checking common SCL pins:");
    for (int i = 0; i < 4; i++) {
      pinMode(common_scl_pins[i], INPUT);
      delayMicroseconds(10);
      int state = digitalRead(common_scl_pins[i]);
      SERIAL_OUT.print("    Pin ");
      SERIAL_OUT.print(common_scl_pins[i]);
      SERIAL_OUT.print(": ");
      SERIAL_OUT.println(state == HIGH ? "HIGH (OK - pull-up present)" : "LOW (ERROR - shorted or no pull-up)");
    }
    
    SERIAL_OUT.println("\n  ANALYSIS:");
    SERIAL_OUT.println("  ✓ I2C pins 18 (SDA) and 19 (SCL) have pull-ups (reading HIGH)");
    SERIAL_OUT.println("  ✗ No I2C devices responding on the bus");
    SERIAL_OUT.println("  → Most likely: IMU not powered OR not connected to pins 18/19");
    
    SERIAL_OUT.println("\n  TROUBLESHOOTING STEPS (in priority order):");
    SERIAL_OUT.println("\n  [CRITICAL] 1. VERIFY IMU POWER:");
    SERIAL_OUT.println("     With multimeter, measure at IMU module:");
    SERIAL_OUT.println("     - VCC pin to GND: Should read ~3.3V (NOT 0V, NOT 5V)");
    SERIAL_OUT.println("     - If 0V: IMU not powered - check power supply connection");
    SERIAL_OUT.println("     - If 5V: Wrong voltage - IMU may be damaged (needs 3.3V)");
    SERIAL_OUT.println("     - If ~3.3V: Power is OK, continue to step 2");
    
    SERIAL_OUT.println("\n  [CRITICAL] 2. VERIFY I2C CONNECTIONS:");
    SERIAL_OUT.println("     With power OFF, check continuity with multimeter:");
    SERIAL_OUT.println("     - IMU SDA pin → Teensy pin 18: Should beep (connected)");
    SERIAL_OUT.println("     - IMU SCL pin → Teensy pin 19: Should beep (connected)");
    SERIAL_OUT.println("     - IMU GND pin → Teensy GND: Should beep (connected)");
    SERIAL_OUT.println("     - If no beep: Wire broken or not connected");
    
    SERIAL_OUT.println("\n  3. CHECK FOR SHORTS (power OFF):");
    SERIAL_OUT.println("     Measure resistance with multimeter:");
    SERIAL_OUT.println("     - SDA to GND: Should be ~4.7kΩ (pull-up), NOT 0Ω");
    SERIAL_OUT.println("     - SCL to GND: Should be ~4.7kΩ (pull-up), NOT 0Ω");
    SERIAL_OUT.println("     - SDA to SCL: Should be open/infinite, NOT shorted");
    SERIAL_OUT.println("     - If 0Ω: Short circuit present");
    
    SERIAL_OUT.println("\n  4. VERIFY IMU IS PRESENT:");
    SERIAL_OUT.println("     - Is the IMU module physically installed?");
    SERIAL_OUT.println("     - Check for broken solder joints on PCB");
    SERIAL_OUT.println("     - If using breakout board, verify all connections");
    
    SERIAL_OUT.println("\n  5. TEST IMU ON DIFFERENT BUS:");
    SERIAL_OUT.println("     If IMU is on Wire1 (pins 17/16), you'll need to modify code");
    SERIAL_OUT.println("     to use Wire1 instead of Wire");
    
    SERIAL_OUT.println("\n  QUICK TEST:");
    SERIAL_OUT.println("  Try disconnecting and reconnecting IMU power while robot is running.");
    SERIAL_OUT.println("  If diagnostic suddenly finds device, it was a power/connection issue.");
    
    return;
  }
  SERIAL_OUT.print("  Found ");
  SERIAL_OUT.print(devicesFound);
  SERIAL_OUT.println(" device(s) on I2C bus");
  
  // Test 2: Check if IMU responds at expected address
  SERIAL_OUT.println("\n2. Testing IMU at address 0x68...");
  Wire.beginTransmission(MPU9250_ADDR);
  uint8_t error = Wire.endTransmission();
  if (error != 0) {
    SERIAL_OUT.print("  ERROR: IMU not responding at 0x68 (error code: ");
    SERIAL_OUT.print(error);
    SERIAL_OUT.println(")");
    SERIAL_OUT.println("  Error codes: 0=OK, 1=data too long, 2=NACK on address, 3=NACK on data, 4=other");
    SERIAL_OUT.println("  Possible causes:");
    SERIAL_OUT.println("    - Wrong I2C address (check AD0 pin - 0x68 if LOW, 0x69 if HIGH)");
    SERIAL_OUT.println("    - Device not powered or in sleep mode");
    SERIAL_OUT.println("    - I2C bus issue");
    return;
  }
  SERIAL_OUT.println("  OK: IMU responds at address 0x68");
  
  // Test 3: Read WHO_AM_I register
  SERIAL_OUT.println("\n3. Reading WHO_AM_I register (0x75)...");
  Wire.beginTransmission(MPU9250_ADDR);
  Wire.write(WHO_AM_I_REG);
  error = Wire.endTransmission(false);
  if (error != 0) {
    SERIAL_OUT.print("  ERROR: Failed to write register address (error: ");
    SERIAL_OUT.print(error);
    SERIAL_OUT.println(")");
    return;
  }
  
  uint8_t bytes_read = Wire.requestFrom((uint8_t)MPU9250_ADDR, (uint8_t)1, (uint8_t)true);
  if (bytes_read != 1) {
    SERIAL_OUT.print("  ERROR: Failed to read WHO_AM_I (got ");
    SERIAL_OUT.print(bytes_read);
    SERIAL_OUT.println(" bytes)");
    return;
  }
  
  uint8_t whoami = Wire.read();
  SERIAL_OUT.print("  WHO_AM_I value: 0x");
  SERIAL_OUT.println(whoami, HEX);
  
  if (whoami == 0x71) {
    SERIAL_OUT.println("  OK: MPU9250 detected (correct ID)");
  } else if (whoami == 0x68) {
    SERIAL_OUT.println("  WARNING: MPU6050 detected (not MPU9250)");
    SERIAL_OUT.println("  This firmware expects MPU9250 with magnetometer");
  } else {
    SERIAL_OUT.print("  ERROR: Unexpected device ID (expected 0x71 for MPU9250, got 0x");
    SERIAL_OUT.print(whoami, HEX);
    SERIAL_OUT.println(")");
    SERIAL_OUT.println("  Possible causes:");
    SERIAL_OUT.println("    - Wrong device connected");
    SERIAL_OUT.println("    - Device malfunction");
    return;
  }
  
  // Test 4: Check Power Management Register
  SERIAL_OUT.println("\n4. Checking Power Management Register (0x6B)...");
  Wire.beginTransmission(MPU9250_ADDR);
  Wire.write(PWR_MGMT_1_REG);
  error = Wire.endTransmission(false);
  if (error != 0) {
    SERIAL_OUT.print("  ERROR: Failed to read PWR_MGMT_1 (error: ");
    SERIAL_OUT.print(error);
    SERIAL_OUT.println(")");
    return;
  }
  
  bytes_read = Wire.requestFrom((uint8_t)MPU9250_ADDR, (uint8_t)1, (uint8_t)true);
  if (bytes_read != 1) {
    SERIAL_OUT.println("  ERROR: Failed to read PWR_MGMT_1");
    return;
  }
  
  uint8_t pwr_mgmt = Wire.read();
  SERIAL_OUT.print("  PWR_MGMT_1 value: 0x");
  SERIAL_OUT.println(pwr_mgmt, HEX);
  
  if (pwr_mgmt & 0x40) {
    SERIAL_OUT.println("  WARNING: Device is in sleep mode (bit 6 set)");
    SERIAL_OUT.println("  Attempting to wake device...");
    Wire.beginTransmission(MPU9250_ADDR);
    Wire.write(PWR_MGMT_1_REG);
    Wire.write(0x00);  // Clear sleep bit
    error = Wire.endTransmission(true);
    if (error == 0) {
      SERIAL_OUT.println("  OK: Device woken up");
      delay(100);  // Wait for device to stabilize
    } else {
      SERIAL_OUT.print("  ERROR: Failed to wake device (error: ");
      SERIAL_OUT.print(error);
      SERIAL_OUT.println(")");
    }
  } else {
    SERIAL_OUT.println("  OK: Device is awake");
  }
  
  if (pwr_mgmt & 0x80) {
    SERIAL_OUT.println("  WARNING: Device reset bit is set (may be resetting)");
  }
  
  // Test 5: Test reading accelerometer/gyro data register
  SERIAL_OUT.println("\n5. Testing accelerometer/gyro data read...");
  Wire.beginTransmission(MPU9250_ADDR);
  Wire.write(0x3B);  // ACCEL_XOUT_H
  error = Wire.endTransmission(false);
  if (error != 0) {
    SERIAL_OUT.print("  ERROR: Failed to set register pointer (error: ");
    SERIAL_OUT.print(error);
    SERIAL_OUT.println(")");
    return;
  }
  
  bytes_read = Wire.requestFrom((uint8_t)MPU9250_ADDR, (uint8_t)14, (uint8_t)true);
  if (bytes_read != 14) {
    SERIAL_OUT.print("  ERROR: Failed to read 14 bytes (got ");
    SERIAL_OUT.print(bytes_read);
    SERIAL_OUT.println(" bytes)");
    SERIAL_OUT.println("  This is the same error occurring during normal operation");
    return;
  }
  
  // Read and display raw values
  int16_t accel_x = (Wire.read() << 8) | Wire.read();
  int16_t accel_y = (Wire.read() << 8) | Wire.read();
  int16_t accel_z = (Wire.read() << 8) | Wire.read();
  Wire.read(); Wire.read();  // Skip temperature
  int16_t gyro_x = (Wire.read() << 8) | Wire.read();
  int16_t gyro_y = (Wire.read() << 8) | Wire.read();
  int16_t gyro_z = (Wire.read() << 8) | Wire.read();
  
  SERIAL_OUT.println("  OK: Successfully read sensor data");
  SERIAL_OUT.print("  Accel (raw): X=");
  SERIAL_OUT.print(accel_x);
  SERIAL_OUT.print(" Y=");
  SERIAL_OUT.print(accel_y);
  SERIAL_OUT.print(" Z=");
  SERIAL_OUT.println(accel_z);
  SERIAL_OUT.print("  Gyro (raw): X=");
  SERIAL_OUT.print(gyro_x);
  SERIAL_OUT.print(" Y=");
  SERIAL_OUT.print(gyro_y);
  SERIAL_OUT.print(" Z=");
  SERIAL_OUT.println(gyro_z);
  
  // Test 6: Check I2C passthrough configuration
  SERIAL_OUT.println("\n6. Checking I2C passthrough configuration...");
  Wire.beginTransmission(MPU9250_ADDR);
  Wire.write(INT_PIN_CFG_REG);
  error = Wire.endTransmission(false);
  if (error != 0) {
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
void loop() {
  const auto nowMicros = micros();

  leftMotor.readCurrent();
  rightMotor.readCurrent();

  // --- Periodic Updates ---
  static auto nextMotionUpdate = nowMicros;
  const unsigned long motionUpdateInterval = 10000;  // 10ms = 100Hz
  if (nowMicros >= nextMotionUpdate) {
    // Update Odometry
    motion.update(leftMotor.getCounter(), rightMotor.getCounter());

    // Update Motor PIDs and apply PWM
    leftMotor.motionUpdate();
    rightMotor.motionUpdate();

    // Calculate next update time, handling potential rollover
    nextMotionUpdate = (nowMicros / motionUpdateInterval + 1) * motionUpdateInterval;
  }

  // --- Drive Control Logic ---
  // This determines the target speeds based on ROS commands or non-ROS targets
  drivecontrol();

  // --- ROS Handling ---
#if ROS
  handleRosAgentState(&rosContext);  // Handles connection and spins the executor
#endif

  // --- Serial Command Input ---
  static char cmdbuf[32];  // Increased buffer size
  static size_t cmdbufpos = 0;
  while (SERIAL_OUT.available()) {
    char c = SERIAL_OUT.read();
    if (c == '\n' || c == '\r') {
      if (cmdbufpos > 0) {         // Process only if buffer is not empty
        cmdbuf[cmdbufpos] = '\0';  // Null terminate
        SERIAL_OUT.print("Received Command: [");
        SERIAL_OUT.print(cmdbuf);
        SERIAL_OUT.println("]");
        parseCommand(cmdbuf);
        cmdbufpos = 0;  // Reset buffer
      }
    } else if (cmdbufpos < (sizeof(cmdbuf) - 1)) {
      cmdbuf[cmdbufpos++] = c;  // Add char to buffer
    } else {
      // Buffer overflow, discard command
      SERIAL_OUT.println("Error: Command too long");
      cmdbufpos = 0;  // Reset buffer
    }
  }

  // --- Encoder Streaming ---
  static auto nextEncoderStream = nowMicros;
  const unsigned long encoderStreamInterval = 10000;  // 10ms = 100Hz for encoder streaming
  if (encoderStreaming && nowMicros >= nextEncoderStream) {
    // Read raw encoder pin states for debugging
    int leftA = digitalRead(PIN_LENCA);
    int leftB = digitalRead(PIN_LENCB);
    int rightA = digitalRead(PIN_RENCA);
    int rightB = digitalRead(PIN_RENCB);
    
    SERIAL_OUT.print("L:");
    SERIAL_OUT.print(leftMotor.getCounter());
    SERIAL_OUT.print("(");
    SERIAL_OUT.print(leftA);
    SERIAL_OUT.print(leftB);
    SERIAL_OUT.print(") R:");
    SERIAL_OUT.print(rightMotor.getCounter());
    SERIAL_OUT.print("(");
    SERIAL_OUT.print(rightA);
    SERIAL_OUT.print(rightB);
    SERIAL_OUT.println(")");
    nextEncoderStream = (nowMicros / encoderStreamInterval + 1) * encoderStreamInterval;
  }

  // --- Periodic Status Output ---
  static auto nextStatusUpdate = nowMicros;
  const unsigned long statusUpdateInterval = 1000000;  // 1 second
  if (nowMicros >= nextStatusUpdate) {
    if (PRINT_MOVES > 1) {
      SERIAL_OUT.println("--- Status Update ---");
      printStatus();
      // Read and print battery voltage
      // Assuming a voltage divider: Vbat -> R1 -> ADC_PIN -> R2 -> GND
      // Voltage = ADC_reading * (AREF / ADC_resolution) * (R1 + R2) / R2
      // Example: Teensy 3.3V AREF, 10-bit ADC (1024), R1=10k, R2=10k -> Factor = 3.3/1024 * 2 = 0.006445
      const float VOLTAGE_FACTOR = 0.00967;  // Teensy 3.3V AREF, R!=2M, R2=1M -> Factor = (3.3/1024) * 3 = 0.00967
      float voltage = analogRead(PIN_VBAT) * VOLTAGE_FACTOR;
      SERIAL_OUT.print("Voltage: ");
      SERIAL_OUT.print(voltage);
      SERIAL_OUT.println(" V");
      SERIAL_OUT.println("---------------------");
    }

    nextStatusUpdate = (nowMicros / statusUpdateInterval + 1) * statusUpdateInterval;
  }
}

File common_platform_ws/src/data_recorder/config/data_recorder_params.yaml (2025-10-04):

data_recorder:
  ros__parameters:
    # Output directory for recorded data
    output_dir: "/home/rcr/teleop_data"
    
    # Topics to record
    camera_topic: "/camera/image_raw"
    cmd_vel_topic: "/cmd_vel"
    
    # Recording parameters
    record_rate: 30.0  # Hz
    image_width: 640
    image_height: 480
    
    # Auto-start recording when node starts
    auto_start: false
    
    # Robot physical parameters (should match your robot config)
    wheel_separation: 0.14048  # meters
    wheel_radius: 0.035        # meters
     
    # Camera configuration
    camera_type: "libcamera"  # "v4l2" or "libcamera"
    camera_id: "0"            # Camera ID for libcamera (0 for first camera)
    pixel_format: ""          # Pixel format (empty for default)

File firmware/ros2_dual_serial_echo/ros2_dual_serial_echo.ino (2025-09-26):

// micro-ROS dual USB-serial Teensy sketch
// - Uses USB Serial (Serial) as the micro-ROS transport
// - Subscribes to /cmd_vel (geometry_msgs/Twist)
// - Echoes received messages to the second USB CDC port (SerialUSB1)

#include <Arduino.h>
#include <micro_ros_arduino.h>

#include <rcl/rcl.h>
#include <rclc/rclc.h>
#include <rclc/executor.h>
#include <rmw/qos_profiles.h>

#include <geometry_msgs/msg/twist.h>

// Ensure your Teensy is configured for "USB Type: Dual Serial" so Serial and SerialUSB1 are available.

// --- Agent connection state machine ---
enum AgentStatus {
  WAITING_AGENT,
  AGENT_AVAILABLE,
  AGENT_CONNECTED,
  AGENT_DISCONNECTED
};

static AgentStatus agentStatus = WAITING_AGENT;

// --- ROS entities ---
static rclc_support_t support;
static rcl_allocator_t allocator;
static rcl_node_t node;
static rclc_executor_t executor;
static rcl_subscription_t sub_cmd_vel; // "/cmd_vel"
static geometry_msgs__msg__Twist msg_cmd_vel;

// --- Macros (same style as micro-ROS examples) ---
#define RCCHECK(fn)                                   \
  {                                                  \
    rcl_ret_t temp_rc = fn;                          \
    if ((temp_rc != RCL_RET_OK)) {                   \
      SerialUSB1.printf("RCL error %d at %s:%d\n",  \
                        (int)temp_rc, __FILE__, __LINE__); \
      return false;                                  \
    }                                                \
  }

#define EXECUTE_EVERY_N_MS(MS, X)                     \
  do {                                               \
    static volatile int64_t init = -1;               \
    if (init == -1) {                                \
      init = uxr_millis();                            \
    }                                                \
    if (uxr_millis() - init > (MS)) {                \
      X;                                             \
      init = uxr_millis();                           \
    }                                                \
  } while (0)

// --- Subscription callback ---
static void cmd_vel_callback(const void *msgin, void * /*context*/) {
  const geometry_msgs__msg__Twist *tw = (const geometry_msgs__msg__Twist *)msgin;
  // Echo to the secondary USB CDC port
  SerialUSB1.print("Twist Received: LinX=");
  SerialUSB1.print((double)tw->linear.x, 6);
  SerialUSB1.print(" AngZ=");
  SerialUSB1.println((double)tw->angular.z, 6);
}

// --- Create/destroy entities ---
static bool create_entities() {
  allocator = rcl_get_default_allocator();
  RCCHECK(rclc_support_init(&support, 0, NULL, &allocator));
  RCCHECK(rclc_node_init_default(&node, "teensy_dual_serial_node", "", &support));

  // Use RELIABLE QoS to match common /cmd_vel publishers
  rmw_qos_profile_t qos = rmw_qos_profile_default;
  qos.reliability = RMW_QOS_POLICY_RELIABILITY_RELIABLE;
  qos.history = RMW_QOS_POLICY_HISTORY_KEEP_LAST;
  qos.depth = 10;
  // Make subscriber durable to receive last latched sample if publisher is transient local
  qos.durability = RMW_QOS_POLICY_DURABILITY_TRANSIENT_LOCAL;
  // Subscribe to absolute topic name
  RCCHECK(rclc_subscription_init(
      &sub_cmd_vel, &node,
      ROSIDL_GET_MSG_TYPE_SUPPORT(geometry_msgs, msg, Twist),
      "/cmd_vel", &qos));

  RCCHECK(rclc_executor_init(&executor, &support.context, 1, &allocator));
  RCCHECK(rclc_executor_add_subscription(&executor, &sub_cmd_vel, &msg_cmd_vel, &cmd_vel_callback, ON_NEW_DATA));
  return true;
}

static void destroy_entities() {
  rcl_subscription_fini(&sub_cmd_vel, &node);
  rclc_executor_fini(&executor);
  rcl_node_fini(&node);
  rclc_support_fini(&support);
}

void setup() {
  // Start both USB CDC ports
  Serial.begin(115200);
  SerialUSB1.begin(115200);
  delay(100);

  SerialUSB1.println("micro-ROS Dual-Serial Echo starting...");

  // Use default USB Serial as the micro-ROS transport
  set_microros_transports();

  // Prepare message memory
  geometry_msgs__msg__Twist__init(&msg_cmd_vel);

  agentStatus = WAITING_AGENT;
}

void loop() {
  switch (agentStatus) {
    case WAITING_AGENT:
      // Poll for agent availability over serial
      EXECUTE_EVERY_N_MS(500, {
        if (RMW_RET_OK == rmw_uros_ping_agent(100, 1)) {
          agentStatus = AGENT_AVAILABLE;
        } else {
          SerialUSB1.println("ROS: WAITING_AGENT");
        }
      });
      break;

    case AGENT_AVAILABLE:
      SerialUSB1.println("ROS: AGENT_AVAILABLE -> creating entities");
      if (create_entities()) {
        agentStatus = AGENT_CONNECTED;
        SerialUSB1.println("ROS: AGENT_CONNECTED");
      // Optional: wait until at least one publisher is matched to /cmd_vel
      size_t pub_count = 0;
      uint32_t t0 = millis();
      while (millis() - t0 < 1000) { // wait up to 1s
        if (rcl_subscription_get_publisher_count(&sub_cmd_vel, &pub_count) == RCL_RET_OK && pub_count > 0) {
          break;
        }
        delay(50);
      }
      SerialUSB1.print("/cmd_vel matched publishers: ");
      SerialUSB1.println((int)pub_count);
      } else {
        destroy_entities();
        agentStatus = WAITING_AGENT;
      }
      break;

    case AGENT_CONNECTED: {
      // Periodically check connection liveness and spin executor
      EXECUTE_EVERY_N_MS(200, {
        if (RMW_RET_OK != rmw_uros_ping_agent(100, 1)) {
          agentStatus = AGENT_DISCONNECTED;
        }
      });
      rclc_executor_spin_some(&executor, RCL_MS_TO_NS(10));
    } break;

    case AGENT_DISCONNECTED:
      SerialUSB1.println("ROS: AGENT_DISCONNECTED -> destroying entities");
      destroy_entities();
      agentStatus = WAITING_AGENT;
      break;
  }
}

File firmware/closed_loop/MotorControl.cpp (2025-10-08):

#include "MotorControl.h"
#include "setup.h"

void MotorControl::applyPWM(int pwmValue) {
  pwmValue = constrain(pwmValue, -MotorControl::MAX_PWM, MotorControl::MAX_PWM);
  static int lastPwm = 0;
  static int lastDir = 0;
  int dir = (pwmValue > 0) - (pwmValue < 0);
  if (dir != lastDir && (abs(pwmValue) > 0 || abs(lastPwm) > 0)) {
#if PRINT_MOVES
    SERIAL_OUT.print(label);
    SERIAL_OUT.print(" dir change ");
    SERIAL_OUT.print((lastDir >= 0) ? (lastDir == 0 ? "0" : "+") : "-");
    SERIAL_OUT.print(" -> ");
    SERIAL_OUT.println((dir >= 0) ? (dir == 0 ? "0" : "+") : "-");
#endif
  }
  if (abs(pwmValue) == MotorControl::MAX_PWM && abs(lastPwm) != MotorControl::MAX_PWM) {
    SERIAL_OUT.print(label);
    SERIAL_OUT.print(" PWM saturated at ");
    SERIAL_OUT.println(MotorControl::MAX_PWM);
  }
  if (pwmValue >= 0) {
    analogWrite(ciPwmA, pwmValue);
    analogWrite(ciPwmB, 0);
  } else {
    analogWrite(ciPwmA, 0);
    analogWrite(ciPwmB, -pwmValue);
  }
  lastPwm = pwmValue;
  lastDir = dir;
}

MotorControl::MotorControl(int pinCurrent, int pinEncA, int pinEncB,
                           int pinPwmA, int pinPwmB, const char *label)
    : ciPinCurrent(pinCurrent), ciPinEncA(pinEncA), ciPinEncB(pinEncB),
      ciPwmA(pinPwmA), ciPwmB(pinPwmB), label(label) {
  resetCounter(); // Initialize state in constructor via reset
  msgcnt = 0;
  prevCounterForSpeed =
      0; // Initialized by resetCounter if called after member init
  prevTimeForSpeed = micros(); // Initialized by resetCounter
}

int32_t MotorControl::getCounter() const {
  int32_t tempCounter;
  noInterrupts();
  tempCounter = counter;
  interrupts();
  return tempCounter;
}

float MotorControl::getSpeed() const { return lastSpeed; }

float MotorControl::getTargetSpeed() const { return targetSpeed; }

void MotorControl::setTargetSpeed(float speed) {
  speed = constrain(speed, -MotorControl::MAX_SPEED, MotorControl::MAX_SPEED);

  if (targetSpeed != speed) {
    targetSpeed = speed;
    // Consider PID reset strategy carefully (e.g., only on sign change or zero
    // crossing) pid.reset(); // Resetting integrator on any change can be jerky

#if PRINT_MOVES
    SERIAL_OUT.print(label);
    SERIAL_OUT.print(" New speed target: ");
    SERIAL_OUT.println(speed);
#endif
  }
}

void MotorControl::resetCounter() {
  noInterrupts();
  counter = 0;
  lastEncTime = micros();
  // Initialize lastEnc based on current pin readings.
  lastEnc = (digitalRead(ciPinEncA) ? 2 : 0) | (digitalRead(ciPinEncB) ? 1 : 0);
  // Reset speed calculation variables
  prevCounterForSpeed = counter; // After counter itself is reset
  interrupts();

  // These are not shared with ISRs, so can be set outside critical section
  lastSpeed = 0;
  targetSpeed = 0;
  mpwm = 0;
  pid.reset();
  prevTimeForSpeed =
      lastEncTime; // Align with lastEncTime from critical section
  SERIAL_OUT.print(label);
  SERIAL_OUT.println(" counters reset");
}
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

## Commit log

2025-09-22 Update template with common_platform name
    [common_platform.urdf.xacro]
2025-09-22 Remove nested xml and robot tags
    [camera.xacro, depth_camera.xacro, face.xacro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]
2025-09-23 Adjust and check static robot visualization
    [camera.xacro, common_platform.urdf.xacro, face.xacro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]
2025-09-26 Combine RCR and PARTs github repositories into 1
    [BOM.csv, Common_Robotics_IMU_Support.stl, power_control.kicad_pcb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]
2025-09-27 adding teensy details
2025-09-30 updated bom
    [BOM.csv]
2025-09-30 Adding arduino-cli config files for proper linking to micro_ros_arduino library
2025-09-30 Add script to place arduino-cli config files
2025-09-30 Update README to correct the Teensy flash instructions
2025-10-02 adding notes about teensy
2025-10-04 Add docs for lidar and mapping
2025-10-04 adding sensors to nav
2025-10-04 camera attach
2025-10-04 add tuning and odometry
2025-10-04 Add launch files for camera
2025-10-04 Fix data recorder launching and ramdisk. Fix camera launch and add image recitifcation launch.
    [RosInterface.cpp]
2025-10-06 Fix sensors package colcon error (no config directory anymore)
2025-10-07 New odom topic relay that changes reliable to best effort transport and adds topic hash
2025-10-07 Add launch file for relay
2025-10-07 Add namespace to frame ids for relay
2025-10-07 Fix timestamp mismatch in relay
2025-10-08 add lidar to nav
2025-10-08 fixing lidar
2025-10-09 teensy programming
2025-10-09 camera operations
2025-10-09 camera details
2025-10-11 adding copy button
2025-10-15 updating bom with pi battery bank
    [BOM.csv]
2025-10-16 Add encoder data streaming
2025-11-17 Rough draft image flipping camera node
2025-11-18 Tested camera node with image flipping
2025-11-18 Training first model is working
    [pyvenv.cfg]
2025-11-18 Add missing Z style variable to the architecture
    [config.yaml, model.py]
2025-11-18 Fix bug during validation
    [model.py]
2025-11-18 Rough draft merge of camera launch file
2025-11-18 Rough draft of position to velocity conversion calibration node
2025-11-18 Print instructions on startup
2025-11-18 Print scan ranges
2025-11-18 Add IMU topic in firmware to improve yaw estimation
2025-11-18 Fix firmware compile time error
    [RosInterface.cpp, closed_loop.ino]
2025-11-18 Add more debugging for IMU publishing in firmware
2025-11-18 Update qos_relay to also relay the imu data from uros
2025-11-18 Add imu_link to the robot description
    [common_platform.urdf.xacro, imu.xacro]
2025-11-18 Remove redundant definition of pi
    [imu.xacro]
2025-11-18 Add imu sensor covariance estimate
2025-11-18 Rough draft firmware update for improved odom using IMU
2025-11-18 Bug fix for resetting odom
    [RosInterface.cpp]
2025-11-18 Add code to correct gyro bias
    [RosInterface.cpp]
2025-12-19 Slower I2C clock and adjustable IMU address at compile time
